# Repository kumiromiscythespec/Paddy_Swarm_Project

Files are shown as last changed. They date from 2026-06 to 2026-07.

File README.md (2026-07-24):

# Paddy Swarm Project Grade 0

田んぼロボットを、まずは無料公開の設計図と試験ログから始めるための公開リポジトリです。

Paddy Swarm Project / 田んぼロボット群プロジェクトは、小規模・家族経営の稲作現場で、人間の負担が大きい作業を小型ロボット群で少しずつ減らすことを目指す試作プロジェクトです。

現段階の目的は、完成品ロボットの販売ではありません。  
まずは **Grade 0** として、3Dプリント用データ、組み立て説明、試験手順、安全ガイド、失敗ログを公開し、興味を持った人が小さく安全に試せる状態を作ります。

---

## 重要：まだ実用機ではありません

このリポジトリのデータは、実験・研究・教育・試作用です。

- 実田んぼで安全に動く保証はありません
- 防水性能は未検証です
- 3Dプリント部品を完全防水容器として信用しないでください
- モーター、バッテリー、制御基板を水に入れる試験は危険です
- 実田んぼは収入源であり、失敗してよい実験場ではありません
- 稲を傷つける可能性のある試験は、必ず小区画・非本番環境から始めてください

推奨する試験順序：

```text
机上
↓
乾いた地面
↓
水槽
↓
柔らかい土
↓
浅泥
↓
水あり模擬環境
↓
小区画・非本番環境
↓
実田んぼ端部
```

---

## Grade 0で公開するもの

- 3Dプリント用STLデータ
- CADデータ置き場
- 組み立て説明書
- 部品番号表
- 推奨フィラメント
- 既製品部品リスト
- 接続テストピース
- サイドフロート試験片
- 浮力試験手順
- 重し配置手順
- 防水BOX配置案
- ギアボックス説明用モデル
- 試験チェックリスト
- 失敗ログ
- 改良履歴

---

## 最初の試験対象

### 1. 接続テストピース

ネジをなるべく使わず、プラモデルのように組み立てるための接続方式を試します。

- スナップフィット
- スライドレール
- 蟻継ぎ
- 印刷ピン
- くさびロック

### 2. サイドフロート断面

水田ローバーが泥や浅水で沈まないための、フロート構造を検討します。

- 密閉空気室
- 発泡材挿入部
- 区画構造
- シャーシ接続レール
- 充電窓逃がし形状

### 3. ギアボックス内部再現モデル

プレゼンや説明に使えるように、左右2モーター、減速ギア、PTO切替、車輪出力、作業ヘッド出力を見える化します。

### 4. 浮力・重心試験用ダミー

電装なしの模型に重しを載せ、水槽で浮力・傾斜・浸水を確認します。

---

## 想定する最小導入：1田スターター

将来的には複数ローバー、充電ステーション、水管理ゲート、直播アーム、除草アーム、高刈り収穫アームへ拡張します。

ただし、最初の導入は **1田スターター** とします。

- ローバー1台
- 基本サイドフロート
- Scout / Field Check Kit
- 交換バッテリー
- 簡易充電・統制ステーション
- スマホ用ローカルWeb UI
- 手動水管理
- 人間回収前提

水管理ゲート、自動ドッキング充電、複数台群制御、ソーラー、直播アーム、高刈り収穫アームは、最初は高級・季節オプションとして扱います。

---

## 将来の拡張構想

### Direct Seeding Arm

育苗工程を減らすための直播アームです。

想定構成：

- 種子ホッパー
- 定量繰り出しローラー
- 浅溝オープナー
- 泥寄せブレード
- 軽鎮圧ローラー

### Weeding Arm

条間中央の初期雑草を処理する除草補助アームです。稲株に近い危険区域は Human Weed Zone として記録し、人間作業に残します。

### High-Cut Harvest Arm

50cm程度の高刈りを標準とする収穫補助アームです。1期目の穂を確保しつつ、茎・葉・節を残し、暖かい年のひこばえ・二番穂を観察します。

### Water Gate

水管理ゲートは高級オプションとして扱います。Grade 0および1田スターターでは、水管理は人間が行います。

---

## リポジトリ構成

```text
.
├── README.md
├── CONTRIBUTING.md
├── .gitignore
├── docs/
│   ├── safety.md
│   ├── test_checklist.md
│   ├── repo_setup_windows.md
│   ├── license_policy.md
│   ├── part_numbering.md
│   └── print_notes/
├── stl/
├── cad/
├── bom/
├── experiments/
├── software/
├── images/
├── tools/
├── print_manifest.csv
└── kit_index.csv
```

---

## 初回印刷の推奨順

1. 接続テストピース
2. サイドフロート断面
3. ギアボックス片側カットモデル
4. 中央シャーシ短縮版
5. 防水BOXダミー
6. Side Charge Zone模型
7. 腹下モジュール交換部
8. ローバー半身モデル
9. 1/2プレゼン模型
10. 実寸フロート試験部品

---

## 協力してほしいこと

- STLを印刷してみる
- PLAとPETGで公差を比較する
- スナップ爪の折れやすさを確認する
- スライドレールのきつさを確認する
- フロート断面の印刷しやすさを確認する
- 水槽で浮力を見る
- 重しを載せて傾き方を見る
- 防水BOX位置の問題を見つける
- ギアボックス模型の説明しやすさを評価する
- 組み立て説明書の分かりにくい点を指摘する
- 失敗ログを共有する

失敗ログは非常に重要です。

---

## 免責

本リポジトリのデータは、実験・研究・教育・試作用です。利用者は自己責任で使用してください。

本プロジェクトは、実田んぼでの動作、防水性能、作物への無害性、収量維持、電気安全、機械安全、法令・農薬ラベル適合性、家畜飼料としての安全性、商用利用時の責任を保証しません。

不明点がある場合は、地域の指導機関、JA、普及指導員、メーカー、専門家に確認してください。

## Common Rover design authority

Current authority: **v2.29.3.9.1**. Start at `CURRENT_COMMON_ROVER_AUTHORITY.md`.

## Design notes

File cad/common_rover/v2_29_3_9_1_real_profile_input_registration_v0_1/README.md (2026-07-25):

# Common Rover v2.29.3.9.1 real profile input registration v0.1

This source-only lane registers two user-confirmed MISUMI purchase records:

- `PROFILE-01`: `NFS5-2020-400`, nominal 20 × 20 mm, 400 mm, quantity 4.
- `PROFILE-02`: `NFSB5-2040-400`, nominal 20 × 40 mm, 400 mm, quantity 4,
  listing colour/finish text `ブラック`.

The order history and supplied Amazon listing references are purchase evidence,
not production cross-section geometry authority. No web lookup is performed.
No customer name, personal order number, shipping address, or payment
information is stored.

Arrival is `PENDING`; measurements, official supplier drawings/tolerances,
accessory compatibility, role assignment, orientation, fit validation, and
structural approval remain `INCOMPLETE` or `HOLD`. Generic MISUMI 5-series
values must not fill missing geometry.

At least two members of each ordered model are assigned separate sample IDs.
The incoming-inspection template records directly accessible external
dimensions at END_A, CENTER, and END_B. Internal cavities and complex slot
geometry require supplier drawings or a separately authorized section cut.

This lane never generates STL, STEP, STP, SVG, or production geometry. All
generated JSON, CSV, Markdown reports, and test results go outside the
repository.

Run with bytecode disabled:

```text
python -B run_unit_tests.py --json <external>/unit_test_results.json --text <external>/unit_test_results.txt
python -B update_production_input_audit.py --repository-root <worktree> --output-dir <external> --baseline-inventory <prior-canonical-artifact>/baseline_tracked_cad_inventory.json
python -B validate_profile_registration.py --repository-root <worktree> --baseline-inventory <prior-canonical-artifact>/baseline_tracked_cad_inventory.json --artifact-dir <external>
```

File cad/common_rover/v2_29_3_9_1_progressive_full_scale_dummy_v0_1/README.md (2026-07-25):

# Progressive Full-Scale Assembly Dummy v0.1

This source-only lane turns the preserved Common Rover v2.29.3.9.1
authority and Assembly Interface v0.1 concepts into a staged, full-scale
placement and fit dummy kit.

The generated parts are not a rover, not load-rated, not waterproof, and not
approved for electrical or field use.  Successful first-side prints remain
usable in the final visual assembly dummy; the workflow does not require a
standalone coupon campaign.

## Authority reuse

`authority_adapter.py` imports the existing corrected Assembly Interface v0.1
authority adapter and reads all controlled dimensions from it.  This lane does
not restate controlled dimensions as independent constants.

The selected architecture is:

- PROFILE-3: printed 20 x 20 envelope-only dummy rails because no supplier
  profile section, T-nut, tolerance, or slot geometry is selected.
- Independent FRONT and REAR BBOX support representations, both marked
  `DUMMY ONLY`, `NO LOAD`, and `NOT STRUCTURAL`.
- Legacy Grade 0 float compatible interface kit with FLOAT-2 visual overlap.
  The audited nominal width is below the registered target, but the
  tolerance/inclination case exceeds it, so operational float-width validation
  remains HOLD.
- Integral positive stops, asymmetric keys, seated indicators, pin windows,
  and a secondary-only retainer cover.

## Physical-connectivity correction

`generate_connectivity_correction.py` preserves the original 19 STL files
byte-for-byte and adds 14 removable, support-free, dummy-only connection
parts.  The resulting 33-part kit has an explicit physical connection graph,
a corrected acyclic print dependency graph, and no loose positioning part.

The correction does not infer PROFILE-3 slots, add direct rail holes, approve
T-nuts, or generate an unknown float body.  Central and float-interface dry
dummy completeness are PASS; float-body and float-equipped completeness
remain HOLD.  AI-10 is reservation-only and remains
`NOT_YET_AUDITED`.

## Printed numbers

The repository precedent `PS-<machine>-<stage>-<category>-<serial>-R00` is
used with machine `PR`, stage `A1`, existing category codes, and a lane-local
300-series allocation.  Since the repository has no global serial allocator,
`GLOBAL_PART_NUMBER_RATIFICATION = HOLD`.

Every exported part is physically engraved with its complete part number and
required orientation/interface/classification markings on a non-functional
identification panel.  Filename-only or metadata-only identification is
rejected.

## Generation

Use the CadQuery environment:

```powershell
C:\Users\yu_ki\Miniforge\envs\paddy-cad\python.exe `
  cad/common_rover/v2_29_3_9_1_progressive_full_scale_dummy_v0_1/generate_dummy_kit.py `
  --output-dir <external-directory>
```

Validation and tests:

```powershell
C:\Users\yu_ki\Miniforge\envs\paddy-cad\python.exe `
  cad/common_rover/v2_29_3_9_1_progressive_full_scale_dummy_v0_1/run_unit_tests.py

C:\Users\yu_ki\Miniforge\envs\paddy-cad\python.exe `
  cad/common_rover/v2_29_3_9_1_progressive_full_scale_dummy_v0_1/validate_dummy_kit.py `
  --artifact-dir <external-directory> --output <external-validation.json>
```

Generated STL, SVG, CSV, JSON, manuals, reports, and caches must stay outside
the repository.

To build and validate the connectivity-corrected artifact:

```powershell
C:\Users\yu_ki\Miniforge\envs\paddy-cad\python.exe `
  cad/common_rover/v2_29_3_9_1_progressive_full_scale_dummy_v0_1/generate_connectivity_correction.py `
  --output-dir <new-external-directory> `
  --baseline-artifact-dir <existing-v0.1-artifact-directory>

C:\Users\yu_ki\Miniforge\envs\paddy-cad\python.exe `
  cad/common_rover/v2_29_3_9_1_progressive_full_scale_dummy_v0_1/validate_connectivity_correction.py `
  --artifact-dir <new-external-directory> `
  --output <new-external-directory>/connectivity_validation.json
```

## Final-gate fixture separation

The base tests accept only manifest schema
`PS_PROGRESSIVE_FULL_SCALE_DUMMY_KIT_V0_1` generated by
`generate_dummy_kit.generate`.  Connectivity tests use the separate
`tests/_connectivity_artifact.py` fixture and accept only schema
`PS_PROGRESSIVE_FULL_SCALE_DUMMY_CONNECTIVITY_CORRECTION_V0_1` generated by
`generate_connectivity_correction.generate`.

`BASE_CORE_OUTPUTS` and `CONNECTIVITY_CORE_OUTPUTS` in
`final_gate_contract.py` are the single authoritative deterministic replay
scopes.  Packaging receipts, test results, checksums, patches, snapshots, and
ZIP files are excluded from core replay.

Run every repository Python command with `python -B` or
`PYTHONDONTWRITEBYTECODE=1`, then scan the complete worktree for `*.pyc`,
`*.pyo`, and `__pycache__`.  Final sealing is performed from an external copy
of `final_gate_sealer.py` plus `final_gate_contract.py`; no repository module
is imported after the final cleanliness scan.

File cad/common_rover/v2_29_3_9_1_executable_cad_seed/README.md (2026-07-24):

# Common Rover v2.29.3.9.1 executable CadQuery seed

This lane is a deterministic, verification-only minimum assembly built from the
sealed `rovers/common_rover/v2.29.3.9.1/` authority. It creates exactly six
axis-aligned CadQuery solids:

1. left FPB rail
2. right FPB rail
3. front crossmember
4. CBOX
5. BBOX
6. battery cassette

The rail and crossmember solids are deliberately classified as
`SIMPLIFIED_TSLOT_AUTHORITY_ENVELOPE`. They are 20 × 20 mm rectangular
verification envelopes, not manufacturing profiles, extrusion selections, or
purchase specifications. No registered maximum-interface-width geometry is
synthesized.

## Run

Use the pinned repository environment:

```powershell
conda run -n paddy-cadquery-280-py312 python -B cad/common_rover/v2_29_3_9_1_executable_cad_seed/validate_seed.py
conda run -n paddy-cadquery-280-py312 python -B cad/common_rover/v2_29_3_9_1_executable_cad_seed/run_unit_tests.py
```

The validator checks single-solid validity, positive finite volume, exact
authority bounding boxes, the two intended rail/crossmember face contacts, zero
unintended volumetric intersections, rail mirror symmetry, the CBOX/BBOX
longitudinal relation, and the three distinct width classes (178 / 286 / 300
mm). Its default STEP roundtrip uses only an operating-system temporary
directory and deletes the file immediately; it never retains a repository STEP
artifact. Pass `--no-step-roundtrip` when only the in-memory gates are needed.

Two dimensionally distinct absolute tolerances are used:

- `linear_tolerance_mm = 1.0e-6` for declared coordinates and bounding boxes.
- `intersection_volume_tolerance_mm3 = 1.0e-9` for Boolean intersection noise
  and verification-only STEP volume replay.

These are exact configuration-contract values. The validator rejects any other
float, including 1.9× or 2× values, NaN, Infinity, zero, and negative values.
The contract values are not compared using themselves as tolerances.

The volume threshold is deliberately much smaller than any modeled feature but
remains a value expressed in mm³; the linear mm tolerance is never reused as a
volume threshold. An intersection volume exactly at the volume tolerance
passes, while any larger volume fails when no volumetric overlap is expected.

Validation is fail-closed. Boolean exceptions, negative/non-finite Boolean
volumes, missing or non-CadQuery objects, and missing/duplicate required
authority records produce structured blockers and `FAIL`. Exception messages,
temporary paths, and memory addresses are not included in deterministic JSON.
Battery placement is confirmed only after all six required hardware-envelope
records have each been found exactly once.

The build result is also closed over the exact six required component IDs.
Missing or extra keys, `None`, another object type, or a non-null solid count
other than six fails validation.

All 15 possible unordered pairs are listed in the report policy matrix. Four
pairs are Boolean checked (the two rail/crossmember contacts, rail separation,
and CBOX/BBOX contact), Battery/BBOX is envelope-checked as
`INTENDED_CONTAINMENT`, and the remaining ten pairs are explicitly
`NOT_AUTHORIZED_FOR_RELATION_ASSERTION`. The reported unintended-intersection
count applies only to the four Boolean-checked pairs; it is not a claim about
unauthorized pairs, and the intentional Battery/BBOX containment overlap is not
counted as unintended.

The successful state is `PASS_WITH_HOLD`. Manufacturing, purchase, field
deployment, waterproofing, structural-strength, executable-CAD release, and
manufacturing-release statuses remain held or unapproved. This seed does not
resolve those authority holds.

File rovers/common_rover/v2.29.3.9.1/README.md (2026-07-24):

# Common Rover v2.29.3.9.1 correction lane

Correction-only authority lane. It unifies lower adapters on rail bottom slots,
upper torque on the front-crossmember top slot, validates all 60 body T-slot
anchors across registries, and resolves the candidate manifest relative to the
version lane. Body geometry, axes, envelopes, width, and release holds remain
identical to v2.29.3.9.

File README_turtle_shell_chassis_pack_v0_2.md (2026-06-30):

# Paddy Swarm Turtle Shell Chassis CAD Pack v0.2

This pack updates the Paddy Swarm amphibious rover test body with a **standard turtle shell cover** and a revised center chassis interface.

## Concept

The turtle shell is now treated as a standard first-defense layer:

- rain guard
- mud splash guard
- shallow waterline / tilt guard
- rollover scuff guard
- future solar/perovskite mounting surface
- mascot/trademark shape

It is **not** treated as the only waterproof enclosure in v0.2. The correct early structure is:

```text
outer standard turtle shell
↓
inner dry cassette / battery cassette
↓
low center battery tray and chassis
```

## Important safety rule

Do not remove the inner waterproof/dry cassette yet. FDM printed shells can leak through layer lines, seams, cracks, screw holes, and cable openings. Use this CAD pack for fit, float, tilt, splash, and handling tests before adding electronics.

## Main files

- `stl/hull_v0_2/PSR-HU-020-R00_center_chassis_segment_v0_2.stl`
- `stl/hull_v0_2/PSR-SHL-001F-R00_standard_turtle_shell_front.stl`
- `stl/hull_v0_2/PSR-SHL-001R-R00_standard_turtle_shell_rear.stl`
- `stl/hull_v0_2/PSR-PWR-010-R00_inner_dry_cassette_dummy.stl`
- `stl/hull_v0_2/PSR-PWR-011-R00_low_center_battery_tray.stl`
- `stl/hull_v0_2/PSR-SHL-003-R00_charge_scute_window_insert.stl`
- `stl/hull_v0_2/PSR-ASM-001-R00_full_rover_turtle_shell_reference_assembly.stl`

## Print priority

1. `PSR-SHL-000-R00_shell_mount_base_gauge.stl` in PLA
2. `PSR-HU-020-R00_center_chassis_segment_v0_2.stl` in PLA
3. `PSR-PWR-010-R00_inner_dry_cassette_dummy.stl` in PLA
4. `PSR-SHL-001F/R` shell halves in PLA for fit check
5. Repeat shell halves in PETG for water-adjacent tests
6. Print `PSR-SHL-003` Charge Scute insert only after confirming top-charge placement

## Bambu Lab A1 note

The shell is split into front/rear halves so printable parts stay near or below the A1 print area. The full assembly STL is a visual reference and is not meant to be printed as one piece.

## Field-use warning

This is Grade 0 / early Grade 1 CAD. Do not mount a live battery or controller until dry tests, splash tests, tilt tests, and paper-towel leak checks are complete.

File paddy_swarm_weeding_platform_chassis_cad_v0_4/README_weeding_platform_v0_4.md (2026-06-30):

# Paddy Swarm Weeding Platform Chassis CAD v0.4

This pack updates the Paddy Swarm work-platform CAD toward a **base chassis + under-belly weeding machine** configuration.

This version intentionally does **not** include the removable direct-seeding / germinated-seed module or the high-cut harvest module. Front and rear option receiver interfaces remain as blank sockets so future modules can be attached without rebuilding the base chassis.

## Design target

- Four-wheel base chassis
- Under-belly weeding module for weeding season
- Removable left/right side floats for shallow-water and mud tests
- Approximately 15 cm water-condition concept, with soft mud sink-in considered
- Low water-shedding protective cover, not a turtle-shaped decorative body
- Charge Scute / top charge area retained
- Solar / perovskite-ready flat area retained, but no solar panel included
- Inner dry cassette retained as second protection layer

## Important safety note

These STL files are Grade 0 / early mechanical test geometry. They are not waterproof-certified and are not validated for real paddy-field operation. Do not mount electronics or batteries for water tests until dry-cassette and leakage tests are completed.

## Print order

1. `PSR-WP-101-R00_base_chassis_four_wheel_weeding_ready.stl`
2. `PSR-WD-101-R00_belly_weeding_module_carrier.stl`
3. `PSR-WD-102-R00_belly_weeding_stirrer_tine_unit.stl`
4. `PSR-FLT-101-R00_removable_side_float_pair_15cm_water.stl`
5. `PSR-WH-101-R00_tpu_low_damage_lug_wheel_dummy.stl`
6. `PSR-WP-102-R00_low_protective_cover_charge_solar_ready.stl`

`PSR-ASM-103` is a reference assembly and is not intended to be printed as one piece.

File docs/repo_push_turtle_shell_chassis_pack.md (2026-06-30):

# Repo push guide: Turtle Shell Chassis v0.2

From your local repository root:

```powershell
cd C:\Paddy_Swarm_Project
Expand-Archive -Path .\paddy_swarm_turtle_shell_chassis_cad_v0_2.zip -DestinationPath . -Force
git status
git add .
git commit -m "Add standard turtle shell chassis CAD v0.2"
git push
```

Recommended commit note:

- Adds standard turtle shell cover concept
- Updates chassis with shell mount rails and inner dry cassette bay
- Adds Charge Scute wireless charge window dummy
- Keeps inner dry cassette as second defense layer

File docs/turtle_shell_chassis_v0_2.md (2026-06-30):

# Paddy Swarm Standard Turtle Shell + Chassis v0.2

## Purpose

This revision changes the turtle shell from a future solar luxury part into a standard protective body cover.

The shell is intended to protect expensive electronics and motors from direct rain, mud splash, shallow waterline contact during tilt, and light rollover scuffing.

## Design decision

The shell is a first defense layer, not the final waterproof container.

```text
Standard Turtle Shell = first defense
Inner Dry Cassette = second defense
Battery Cassette = protected power module
Chassis = low-center structure and float/motor interface
```

## Why the chassis needed an update

A standard shell requires new hardpoints:

- shell mount rails
- orientation key so the shell cannot be installed backwards
- inner dry cassette bay
- low-center battery tray interface
- charge module / charge scute reserved area
- future solar-ready surface planning

## Charge Scute

The Charge Scute is a non-metallic window zone for future top wireless charging.

Rules:

- do not put metal screws near the coil window
- do not charge directly into a lithium battery
- use a receiver module, voltage regulation, CC/CV charger, BMS, fuse, and temperature monitoring
- keep cassette charging and wired charging compatible through the common Power Bay concept

## Solar-ready shell

The v0.2 shell does not include solar panels. It only reserves upper surface area for:

- future removable solar panel mount
- perovskite coating experiments
- adhesive panel tests

The rover must remain fully useful without solar.

## Tilt and waterline test

Recommended first tests:

1. Mount shell to chassis with no electronics.
2. Put paper towels inside the dry cassette dummy.
3. Add ballast equivalent to expected electronics/battery weight.
4. Float in water tray/tank.
5. Tilt to 5°, 10°, and 15°.
6. Confirm water runs off the shell and does not pool.
7. Confirm no water drips into the dry cassette zone.
8. Log whether shell lips touch water and whether the rover self-righting tendency worsens.

## Remaining risks

- Shell raises center of gravity if printed too thick.
- Shell can catch wind.
- Shell can hold heat if ventilation is poor.
- Shell can trap condensation if sealed incorrectly.
- FDM print layer lines are not waterproof by default.
- Motor shaft exits still need separate mud and water guards.

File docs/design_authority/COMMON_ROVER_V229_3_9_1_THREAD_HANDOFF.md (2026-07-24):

# Common Rover v2.29.3.9.1 cross-thread handoff

Correction-only authority. CBOX/BBOX/cassette, rails, crossmember, axes,
envelopes, 286 mm operational width, output Y=-222…-212, and release holds are
unchanged from v2.29.3.9. Lower adapters are BOTTOM_SLOT on RAIL-L/R-BOTTOM.
Upper torque is XMEMBER-TOP / TOP_SLOT_OF_FRONT_CROSSMEMBER. Cross-registry
validation is explicit and complete for 60/60 anchors.

Copyable: `Authority=v2.29.3.9.1; correction-only; lower=BOTTOM_SLOT; upper-torque=XMEMBER-TOP; cross-registry=60/60; width=286; CAD/manufacturing=HOLD.`

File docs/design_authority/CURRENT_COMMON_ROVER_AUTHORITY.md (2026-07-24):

# Design authority pointer

Current Common Rover authority: **v2.29.3.9.1**.

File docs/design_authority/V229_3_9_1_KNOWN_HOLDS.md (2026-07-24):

# Known holds

CadQuery/actual solids/STEP/STL are not run. Exact T-slot/T-nut product,
strength, waterproofing, electrical safety, thermal behavior, manufacturing,
purchase, and field deployment remain unapproved or unvalidated.

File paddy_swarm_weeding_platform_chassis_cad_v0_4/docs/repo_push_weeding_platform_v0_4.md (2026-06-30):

# Push Paddy Swarm Weeding Platform v0.4 to GitHub

```powershell
cd C:\Paddy_Swarm_Project
Expand-Archive -Path .\paddy_swarm_weeding_platform_chassis_cad_v0_4.zip -DestinationPath . -Force
git status
git add .
git commit -m "Add weeding platform base chassis CAD v0.4"
git push
```

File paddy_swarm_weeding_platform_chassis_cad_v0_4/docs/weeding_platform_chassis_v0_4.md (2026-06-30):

# Paddy Swarm Weeding Platform Chassis v0.4

## What changed from v0.3

v0.3 tried to represent a generic work platform with direct seeding, belly weeding, and high-cut harvesting examples. In this v0.4 CAD pack, the design is narrowed to the **weeding-season complete configuration**:

- Base chassis
- Four wheels
- Removable side floats
- Low protective cover
- Inner dry cassette
- Under-belly weeding module

The following are **not included as physical modules** in this pack:

- Germinated-seed direct-seeding module
- High-cut harvest arm

Only the blank front/rear receiver sockets remain.

## Field assumptions

- Water depth target for concept review: around 15 cm
- Soft mud sink-in is expected
- Wheels may partly sink; side floats help maintain buoyancy and side protection
- Under-belly weeding module should disturb weeds and surface mud, but not dig aggressively
- 180-degree rotation in crop lanes remains discouraged; Reverse-First Navigation is still assumed

## Mechanical philosophy

The rover is a paddy-field work platform, not a turtle-shaped vehicle. The cover is low and functional. The shell-like cover is used for water-shedding and protection only.

The side floats are removable because they may not be needed for every test, and the user should be able to compare:

- base chassis without floats
- base chassis with floats
- float size variations
- float position variations

## Weeding module concept

The under-belly weeding module is represented by:

- slide-in carrier frame
- height-adjustment posts
- mud float skids
- stirrer axle
- flexible tine array
- guard bars

The module is intended for print-fit and clearance testing first. Rotation, PTO, motor coupling, sealing, and weed effectiveness require separate experiments.

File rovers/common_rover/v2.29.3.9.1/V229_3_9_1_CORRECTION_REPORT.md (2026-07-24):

# v2.29.3.9.1 correction report

- Lower adapter: `BOTTOM_SLOT`, host slots `RAIL-L-BOTTOM` / `RAIL-R-BOTTOM`.
- Upper torque: `XMEMBER-TOP`, normalized `TOP_SLOT`, semantic role
  `TOP_SLOT_OF_FRONT_CROSSMEMBER`.
- Join: explicit `slot_zone_id`; no fallback or component-name inference.
- Validation: source-relative and independent of current working directory.

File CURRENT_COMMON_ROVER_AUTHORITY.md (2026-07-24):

# Current Paddy Swarm Common Rover Authority

Current authority: **v2.29.3.9.1**

Precedence: v2.29.3.9.1 > v2.29.3.9 > v2.29.3.8 > v2.29.3.7 > v2.29.3.6 > v2.29.3.5 > v2.28.2

This is a correction-only revision of the v2.29.3.9 FPB 20×20 T-slot frame.
Lower adapters use BOTTOM_SLOT; upper torque uses XMEMBER-TOP; all 60/60 body
T-slot anchors pass explicit cross-registry validation.

Body dimensions and the 138×20×20 mm front crossmember are unchanged. Registered
maximum-interface width is 286 mm. Actual solid is not run.

GITHUB_EXECUTABLE_CAD_RELEASE = HOLD
GITHUB_MANUFACTURING_RELEASE = HOLD
PURCHASE_STATUS = NOT_APPROVED
FIELD_DEPLOYMENT_STATUS = NOT_APPROVED

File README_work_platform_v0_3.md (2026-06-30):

# Paddy Swarm Work Platform Chassis CAD Pack v0.3

田植え直撒き・腹下除草・高刈りアームに対応するため、亀の体に似せることよりも、作業モジュールを載せるための四輪作業プラットフォームとして再設計したCAD/STLパックです。

## 設計目的

- 中央 Safety Path 運用を前提にした四輪低重心ローバー
- 前方に除草・直播・田植え系アタッチメントを接続
- 腹下に除草撹拌ユニットを搭載
- 後方に高刈り・収穫補助アームを接続
- 上面は亀型マスコット優先ではなく、低い防水・防泥カバーとして整理
- Charge Scute / ソーラー対応面は残すが、作業機能を優先

## 注意

このパックは Grade 0 / R00 の概念・寸法確認用です。実田んぼ投入、電装搭載、水没試験には使わないでください。FDM印刷品は完全防水ではありません。

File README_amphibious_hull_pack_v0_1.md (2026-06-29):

# Paddy Swarm Amphibious Hull CAD Pack v0.1 / 水陸両用型ローバー船体CADパック

This pack adds the first printable CAD/STL set for the Paddy Swarm Amphibious Hull concept.

このパックは、Paddy Swarm Project の「水陸両用型ローバー船体 v0.1」をGrade 0試験用に3Dプリントできる形へ落としたものです。

## Important / 重要

These parts are **experimental Grade 0 parts**. They are not waterproof, not field-proven, and not a finished rover.

- Do not put electronics or batteries in water.
- Do not use these parts in a real paddy field first.
- Start with PLA fit checks, then PETG water-tank tests.
- Use foam inside float trays during water tests.
- Seal seams only for controlled tests using tape/silicone.
- If a paper towel placed in the waterproof-box position gets wet, the design fails the water-ingress test.

## Contents

- `stl/hull_v0_1/` — printable STL files
- `cad/hull_v0_1/generate_amphibious_hull_v0_1.py` — source generator used to create the STL files
- `docs/amphibious_hull_v0_1.md` — design notes and assembly concept
- `docs/print_notes/PSR-HU-R00.md` — print notes
- `print_manifest.csv` — part sizes and print notes
- `kit_index.csv` — repo index entries

## First print recommendation

Print in this order:

1. `PSR-HU-001-R00_central_hull_short_frame.stl` in PLA
2. `PSR-HU-013-R00_ballast_test_tray.stl` in PLA
3. One float tray, e.g. `PSR-HU-003-R00_left_float_mid_tray.stl`, in PLA
4. Same float tray in PETG
5. Float lid and seam joiner clips
6. Water-tank test with no electronics

## Repository merge

From the repo root:

```powershell
Expand-Archive -Path .\paddy_swarm_amphibious_hull_cad_v0_1.zip -DestinationPath . -Force
git add .
git commit -m "Add amphibious hull Grade 0 CAD pack v0.1"
git push
```

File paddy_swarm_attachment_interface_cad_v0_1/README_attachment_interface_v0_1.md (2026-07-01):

# Paddy Swarm Attachment Interface CAD v0.1

This package introduces the **Paddy Swarm Attachment Interface Standard v0.1**.

Purpose:
- Keep the rover body upgradable while keeping attachment locations fixed.
- Move direct seeding / planting-style modules to the **rear** so the rover wheels do not run over freshly placed germinated seed.
- Reserve the **front** attachment ports for high-cut harvest, camera-linked work, and operations that need visual confirmation.
- Keep belly weeding as a central underbody module.

Important: this is a **Grade 0 / mock-up CAD pack**. Shafts, pins, bushings and springs are included as 3D-printable dummy parts so a physical model can be assembled cheaply. Field-use versions may need metal shafts, bearings, bushings, springs, seals, and stronger hardware.

## Fixed interface concept

Coordinate convention:
- X: left/right
- Y: front/rear
- Z: up/down
- Body center is the origin.

Nominal fixed positions:
- Front-left port: X=-70 mm, Y=+230 mm
- Front-right port: X=+70 mm, Y=+230 mm
- Rear-left port: X=-70 mm, Y=-230 mm
- Rear-right port: X=+70 mm, Y=-230 mm
- Nominal port height: Z=65 mm

These values are the v0.1 interface reference. Future rover chassis updates should preserve these port positions or provide adapter plates.

## Attachment allocation rule

- Front two ports: high-cut harvest, camera-linked tools, inspection tools.
- Rear two ports: direct seeding, planting, replanting modules.
- Belly rail: underbody weeding modules.
- Side mounts: floats, guards, recovery aids.

## Included update

- Base chassis v0.5 with four fixed ports.
- Rear-mounted 3-unit direct seeding mock-up using the rear-left and rear-right ports.
- Front high-cut interface bridge gauge, not an actual cutter.
- 3D-printed dummy shafts, pins, springs and fasteners for low-cost model assembly.
- Stackable hopper extension walls with no lid, assuming wet germinated seed and non-rain-avoidance operation.

## Notes

The direct seeding module here is intentionally placed at the rear. It is meant to place germinated seed after the wheels pass, closer to the logic of a transplanter. The module includes a light skid/opener concept for shallow placement and wheel-track correction, but actual seed depth must be validated in tray and mud tests.

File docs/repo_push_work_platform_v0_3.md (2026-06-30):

# GitHub push手順

ローカルの `C:\Paddy_Swarm_Project` にZIPを置いた前提です。

```powershell
cd C:\Paddy_Swarm_Project
Expand-Archive -Path .\paddy_swarm_work_platform_chassis_cad_v0_3.zip -DestinationPath . -Force
git status
git add .
git commit -m "Add four-wheel work platform chassis CAD v0.3"
git push
```

## 推奨コミット内容

- `stl/work_platform_v0_3/`
- `cad/work_platform_v0_3/generate_work_platform_v0_3.py`
- `docs/work_platform_chassis_v0_3.md`
- `docs/print_notes/PSR-WP-R00.md`
- `print_manifest_work_platform_v0_3.csv`
- `kit_index_work_platform_v0_3.csv`

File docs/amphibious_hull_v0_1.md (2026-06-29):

# docs/amphibious_hull_v0_1.md

# Paddy Swarm Amphibious Hull v0.1

## Purpose

This is the first Grade 0 CAD pack for the Paddy Swarm amphibious hull concept.

Design principle:

```text
Instead of attaching floats to a vehicle,
design a floating small hull and attach drive/working modules to it.
```

日本語で言えば、これは「車体にフロートを足す」のではなく、**浮く船体に足回りと作業アームを付ける**設計です。

## Target

- 30cm rice-row spacing awareness
- Narrow hull, around 220–240mm max concept width
- Left/right side floats as primary buoyancy
- Low center of gravity
- Open-top float trays for foam insertion and inspection
- No electronics during Grade 0 water tests

## Parts

| Part No. | Name |
|---|---|
| PSR-HU-001-R00 | Central hull short frame |
| PSR-HU-002-R00 | Left float front tray |
| PSR-HU-003-R00 | Left float mid tray |
| PSR-HU-004-R00 | Left float rear tray |
| PSR-HU-005-R00 | Right float front tray |
| PSR-HU-006-R00 | Right float mid tray |
| PSR-HU-007-R00 | Right float rear tray |
| PSR-HU-008-R00 | Bow mud deflector concept |
| PSR-HU-010-R00 | Waterproof box dummy |
| PSR-HU-012-R00 | Belly module rail sample |
| PSR-HU-013-R00 | Ballast test tray |
| PSR-HU-015-R00 | Generic float segment lid |
| PSR-HU-016-R00 | Float seam joiner clip |

## Float structure

Each float segment is an open tray with:

- bottom plate
- side walls
- internal baffles
- foam insertion space
- waterline raised bands
- lid part
- seam clips for multi-segment tests

This is not a sealed boat hull. It is a Grade 0 test structure.

## Buoyancy test concept

Use no electronics. Put foam inside trays, mount lids, temporarily seal seams with tape or silicone, then test in a water tank.

Minimum checks:

```text
normal posture
front-up 10 degrees
front-down 10 degrees
left tilt 10 degrees
right tilt 10 degrees
light rocking
paper towel at waterproof-box position
```

Pass condition:

```text
paper towel stays dry
waterline stays below danger area
no sudden sinking if one segment leaks
```

## Print notes

- PLA: fit test and visual test
- PETG: water-tank test parts
- TPU: not used in this pack
- Use brim for tall float trays
- Print float trays upright/open-side up
- Do not assume FDM parts are watertight

## Next iteration ideas

- Add readable embossed labels
- Improve seam connector geometry
- Add true dovetail keys
- Create scaled full assembly jig
- Add optional wide-test float
- Add side-charge cutout version
- Add watertight lid gasket channel

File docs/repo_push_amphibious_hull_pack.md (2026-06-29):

# docs/repo_push_amphibious_hull_pack.md

# How to add this CAD pack to the public repo

Put `paddy_swarm_amphibious_hull_cad_v0_1.zip` in your repo root, for example:

```text
C:\Paddy_Swarm_Project
```

Then run PowerShell:

```powershell
cd C:\Paddy_Swarm_Project
Expand-Archive -Path .\paddy_swarm_amphibious_hull_cad_v0_1.zip -DestinationPath . -Force
git status
git add .
git commit -m "Add amphibious hull Grade 0 CAD pack v0.1"
git push
```

If the ZIP file itself appears in `git status`, do not commit the ZIP. Commit the extracted files only.

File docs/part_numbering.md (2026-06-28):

# Part Numbering

## Machine codes

- PR = Paddy Rover
- PP = Paddy Planter
- HU = Harvest Unit
- WU = Weeding Unit
- ST = Station
- PB = Power Box
- SC = Solar Carapace

## Stage codes

- A0 = Alpha-0
- A1 = Alpha-1
- R0 = Row-0
- P0 = Planter-0
- H0 = Harvest bench test
- W0 = Weeding bench test
- S0 = Station prototype

## Category codes

- BDY = Body / exterior
- FRM = Frame
- MNT = Mount
- CBL = Cable guide
- FND = Fender
- FLT = Float
- SKD = Skid
- WHL = Wheel
- PAD = Foot pad
- ARM = Arm
- GDE = Guide
- CVR = Cover
- BOX = Box holder
- TRAY = Tray
- DOCK = Dock part
- SEN = Sensor mount
- CAM = Camera mount
- BAT = Battery tray
- SBC = Single board computer mount
- CHU = Chute
- DEPTH = Depth gauge

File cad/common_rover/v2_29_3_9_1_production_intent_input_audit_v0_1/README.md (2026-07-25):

# Common Rover v2.29.3.9.1 production-intent input audit v0.1

This source-only lane audits whether real manufacturing inputs exist before any
production-intent geometry is generated. It does not create STL, STEP, STP, or
SVG files. All generated reports must be written outside the repository.

The existing 33 progressive full-scale dummy STL files remain `DUMMY ONLY / NO
LOAD / NOT STRUCTURAL / PROFILE-3 ONLY`. They are not manufacturing parts,
real-rover parts, structural parts, or evidence of compatibility with an
actual aluminum extrusion. Their geometry and part numbers are not
automatically reusable, and removing the dummy marking does not promote them
to production.

The corrected repository-output contract permits the 181 tracked STL and 109
tracked STEP/STP files sealed at base
`242737507c1f94811ff309b36905525057761c45`, provided every baseline file is
unchanged. Added, modified, deleted, or untracked CAD output fails the audit.
The filesystem scan is independent of `.gitignore`.

The canonical inventory algorithm is
`SHA256_OF_UTF8_BYTEWISE_SORTED_POSIX_PATH_RECORDS_V1`:

1. convert backslashes to `/`, reject leading `./`, absolute paths,
   noncanonical segments, control characters, and duplicate canonical paths;
2. validate every file SHA-256 and lowercase it;
3. sort records by `record["path"].encode("utf-8")`;
4. encode each record as
   `<lowercase_sha256><two ASCII spaces><canonical_posix_path><LF>`;
5. concatenate the UTF-8 bytes and SHA-256 the complete payload.

The JSON record array and CSV rows must be identical and in that canonical
order. The receipt, recorded JSON hash, calculated hash, and independent
reversed/shuffled replays must all match.

Run with bytecode disabled:

```text
python -B build_canonical_baseline_inventory.py --repository-root <worktree> --output-dir <external>
python -B replay_canonical_inventory.py --artifact-dir <external>
python -B run_unit_tests.py --json <external>/unit_test_results.json --text <external>/unit_test_results.txt
python -B generate_production_input_audit.py --repository-root <worktree> --output-dir <external> --baseline-inventory <external>/baseline_tracked_cad_inventory.json
python -B validate_production_input_audit.py --repository-root <worktree> --artifact-dir <external>
```

Expected outcome is `PASS_WITH_HOLD`: the audit is valid, but production STL
generation, manufacturing, purchase, and field deployment remain unapproved
until all actual inputs are closed.

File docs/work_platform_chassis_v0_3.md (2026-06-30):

# Paddy Swarm Work Platform Chassis v0.3

## 変更理由

前回の標準亀甲羅ローバー案は、ブランド性・水切り・防泥ガードとして有効でした。  
しかし、実際の目的は「亀に似た車体」を作ることではなく、以下の作業に対応できる低コストな水田作業プラットフォームを作ることです。

- 田植え・直播
- 腹下除草
- 高刈り収穫補助
- 前進作業、後退帰還
- Safety Path から左右作業レーンへ入る運用

そのため v0.3 では、外観よりもアタッチメント接続・腹下空間・低重心・四輪レイアウトを優先しました。

## 基本構成

| 部品 | 目的 |
|---|---|
| PSR-WP-001 | 四輪作業シャーシ本体。腹下モジュールレール、前後マウント、低重心トレーを含む |
| PSR-WP-002 | 前方クイックアタッチメントマウント。除草・直播・田植え系を想定 |
| PSR-WP-003 | 後方マウント。高刈り・収穫補助・後部処理系を想定 |
| PSR-WP-004 | 腹下除草モジュールのダミー。撹拌軸・タインのクリアランス確認用 |
| PSR-WP-005 | 直播・田植えモジュールダミー。ホッパー・繰り出し・浅溝オープナーを想定 |
| PSR-WP-006 | 高刈り収穫アームダミー。刈刃・穂ガイド・受けトレーを想定 |
| PSR-WP-007 | 低い機能優先カバー。水切り、Charge Scute、ソーラー対応面を含む |
| PSR-WP-008 | 側面フロートペア。Safety Path幅での安定化想定 |
| PSR-WH-010 | TPUラグタイヤのダミー |
| PSR-ASM-002 | 全体参照アセンブリ。印刷用ではなく全体把握用 |

## 重要な設計方針

### 四輪化

1輪を各コーナーに配置します。  
差動制御・左右駆動・将来の四輪独立制御を検討できますが、R00ではまず見た目と配置の確認用です。

### 前方マウント

前方には以下の作業を想定したクイックマウントを置きます。

- 除草用前方ガイド
- 直播ユニット
- 小苗田植え/補植ユニット
- 浅溝オープナー
- 種子ホッパー

### 腹下除草

腹下には除草撹拌ユニットを通せる中央クリアランスを残します。  
R00では撹拌軸ダミーとタインダミーを入れ、地面・泥面との干渉確認を目的にします。

### 後方高刈りアーム

後方には高刈り・収穫補助のためのヒンジ耳とマウントを置きます。  
初期は穂先を切る・受ける・後方処理系に渡すための空間検討用です。

### 低い保護カバー

亀の体に似せるのではなく、低い水切りカバーとして再定義しています。  
上面には以下を残します。

- Charge Scute 予定地
- ソーラー後付け/ペロブスカイト塗布予定面
- 左右水切りリップ

ただし、カバーは第一防衛層です。内部防水カセットはまだ必要です。

## 試験順序

1. PSR-WP-001 をPLAで印刷し、反り・サイズ感・腹下クリアランスを確認
2. PSR-WP-002 / 003 を印刷し、前後マウントの位置を見る
3. PSR-WP-004 を腹下へ仮置きし、除草タインの地面干渉を見る
4. PSR-WP-005 を前方へ仮置きし、重心変化を見る
5. PSR-WP-006 を後方へ仮置きし、後方アームで転倒しないか確認
6. PSR-WP-007 を載せ、水切り・アクセス性・充電窓位置を見る
7. PSR-ASM-002 は印刷せず、全体把握・レンダリング用に使う

## 現場上の注意

- この形はSafety Path運用を前提にする
- 条間に入って作業し、基本は後退帰還する
- 180度その場旋回は標準禁止
- 腹下除草ユニット使用中の旋回は避ける
- 高刈りアームは重心を後ろに動かすので、必ずダミー荷重で確認する
- 直播ホッパーは種子量により重心が変わる

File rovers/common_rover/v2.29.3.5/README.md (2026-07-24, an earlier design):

> [!WARNING]
> **Status: EXPERIMENTAL_PREFLIGHT_SOURCE**
>
> This revision is a design-authority and pre-CadQuery validation snapshot.
> CadQuery/OCP execution has not yet been performed.
>
> No actual Solid, STEP, STL, rendered PNG, collision result,
> minimum-assembly result, structural-strength result, waterproof result,
> manufacturing release, purchase approval, or field-deployment approval
> is provided by this revision.
# Common Rover v2.29.3.5

Contract:
`PS-COMMON-ROVER-V229_3_5-LOOP001-HOLE-AUTHORITY-FULL-RUNNER-WIRING-CLOSURE-001`

This isolated lane determines rail-hole responsibility from attachment, joint,
load-path, part-role, and measurement authority before any reachability check.
Unreachable instances are never silently converted to stale records and no
coordinate is moved without authority.

The 24 rail-referencing instances account as:

- four required FG-006 rail through holes;
- eight measurement holds in FG-002 and FG-004;
- twelve design contradictions in FG-008, FG-009, and FG-020.

Static full-circle inspection identifies four interior candidates, five
edge-breakout candidates, and fifteen exterior/contradiction candidates. The
five boundary circles are not generated as normal holes or reinterpreted as
slots/notches.

`full_loop_runner.py` is the single 24-stage execution authority. It wires
required-hole generation, STEP reimport, visualization STL validation, actual
Solid rendering, minimum-assembly propagation, receipt consumption, final
gate, package, and final ZIP seal. CadQuery absence exits 20 and never claims
Solid, STEP, STL, PNG, or assembly PASS.

The rail remains `METAL_PART_CAD_VALIDATION`, not a production print target.
The rail/front-crossmember joint remains `UNDEFINED_MEASUREMENT_HOLD`, so
minimum-assembly and LOOP-001 final PASS are blocked.

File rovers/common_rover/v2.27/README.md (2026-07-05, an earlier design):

# Paddy Swarm Common Rover v2.27

## 日本語

### 概要

このフォルダは、Paddy Swarm Project / 田んぼロボット群プロジェクト向けの **Common Rover v2.27** 印刷・組み立て用データです。

v2.27は、実田んぼ投入機ではなく、以下を確認するための **低負荷3Dプリント模型 / 試作検証機** です。

- 足回りの組み立て確認
- ギアボックス内部模型の確認
- TPU一体タイヤの取り付け確認
- BBOX / CBOX の前後配置確認
- PTOと緊急停止ボタンの干渉確認
- フロート装備時の浮力・姿勢確認
- 15cm水深を想定した水槽・たらい試験
- 部品干渉、組み立て順、修正点の発見

このデータは、完成品・実用品・防水保証品ではありません。

---

### 重要な安全注意

このv2.27は、**組み立て確認・浮力確認・干渉確認用の低負荷3Dプリント模型**です。

以下を必ず守ってください。

- 電子部品を搭載した状態で水試験をしないでください。
- 実田んぼに投入しないでください。
- 3Dプリント防水BOXを、そのまま実用防水筐体として扱わないでください。
- 水試験では、バッテリー・基板・モーターを入れず、重りで重量だけを再現してください。
- 15cm水深試験では、フロート装備を必須としてください。
- PTO、モーター駆動、バッテリー、防水、充電系、非常停止系は実地検証済みではありません。
- 緊急停止ボタンは、PTOユニット装着時でも必ず押せる位置にしてください。
- フロートは標準装備として扱いますが、実際に浮くかどうかは水槽試験で確認してください。

---

### v2.27の重要設計方針

#### 1. BBOX / CBOX は前後方向に配置する

BBOX-BDY と CBOX-BDY は、車体の左右方向に並べてはいけません。

正しい配置:

```text
前方 FRONT
  BBOX-BDY  電源 / バッテリー系
  CBOX-BDY  制御 / 通信系
後方 REAR
```

禁止配置:

```text
BBOX-BDY + CBOX-BDY を左右横並び
```

横並びにすると、30cm条間の幅制限を超える可能性が高くなります。

---

#### 2. タイヤは別体ゴムタイヤ前提ではない

v2.27の以下の部品は、TPUで印刷する **一体タイヤ / 接地ホイール模型** です。

```text
PS-RV227-WHL-FL
PS-RV227-WHL-FR
PS-RV227-WHL-RL
PS-RV227-WHL-RR
```

市販ゴムタイヤを別途履かせる設計ではありません。

将来的に市販ゴムタイヤ仕様にする場合は、別バージョンとして、ホイールリム・タイヤ内径・外径・ビード形状を再設計してください。

---

#### 3. フロートは標準装備

15cm水深 + 泥への沈み込みを想定すると、タイヤと防水BOXだけでは水没リスクがあります。

v2.27では、以下のフロート関連部品を標準装備として扱います。

```text
PS-RV227-FLT-L
PS-RV227-FLT-R
PS-RV227-HULL-SKID
PS-RV227-FLT-BRACKET-S
PS-RV227-FLT-RCV-L
PS-RV227-FLT-RCV-R
PS-RV227-FLT-RCV-FR-S
PS-RV227-FLT-STRAP-S
```

ただし、3Dプリント品は積層隙間やピンホールから浸水する可能性があります。

水試験では、必要に応じて以下を併用してください。

- 発泡材
- 密閉PETボトル
- EVA / 発泡ブロック
- 防水塗装
- エポキシ封止
- ウレタンコート
- シリコンシール

---

#### 4. PTOと緊急停止ボタンは分離する

v2.27では、PTO接続部と緊急停止ボタンの干渉を避けるため、以下の方針にしています。

- PTOは前面下側の接続部に配置
- 緊急停止ボタン / 操作パネルは高置き
- `PS-RV227-RCP-BRKT` により、操作パネルをPTOから離す
- PTOユニットを装着した状態でも、緊急停止ボタンを押せることを必須条件とする

---

### 推奨印刷セット

このフォルダには、複数の印刷セットが含まれる場合があります。

低負荷の稼動模型として印刷する場合:

```text
dense_rigid_plus_metal
dense_tpu_only
```

実物の金属軸を用意する場合:

```text
dense_rigid_only
dense_tpu_only
```

注意:

```text
dense_rigid_plus_metal と dense_rigid_only を両方印刷しないでください。
部品が重複します。
```

---

### 材料と印刷量の目安

撮影されたスライサー表示を元にした概算では、v2.27一式は以下の規模です。

```text
PETG/PLA:
  約 84h22m
  約 2781.91g

TPU:
  約 21h05m
  約 302.32g

合計:
  約 105h27m
  約 3084.23g
```

実際の印刷時間と材料量は、プリンター、ノズル径、積層ピッチ、インフィル、サポート設定、フィラメント種類によって変わります。

---

### 組み立て前の確認

印刷前・組み立て前に、必ず以下を確認してください。

```text
1. BBOX/CBOXが前後方向に配置されているか
2. 横並びBOX配置になっていないか
3. WHL系がTPU一体タイヤとして扱われているか
4. フロート部品が印刷対象に含まれているか
5. RCP-G1操作パネルがPTOと干渉しない位置にあるか
6. PTOユニット装着時でも緊急停止ボタンを押せるか
7. フロートとタイヤが干渉しないか
8. ギアボックス内部模型の向きが左右で合っているか
9. 配線穴・上部ノッチが水面に近づきすぎないか
10. 水試験では電子部品を外しているか
```

---

### 水槽・たらい浮力試験の推奨手順

最初の水試験では、電子部品を搭載しないでください。

推奨手順:

```text
1. LOWER-FRAME、タイヤ、フロート、HULL-SKIDを組む
2. BBOX/CBOXを載せる
3. 電子部品の代わりに重りを入れる
4. 15cm水深のたらい・浴槽・水槽に入れる
5. 静止時の水線を確認する
6. 前後に傾ける
7. 左右に傾ける
8. 軽く揺らす
9. 配線穴・フタ・BOX底面に水が近づくか確認する
10. 浮力不足ならフロート・発泡材・前後浮力体を追加する
```

合格目安:

```text
- BOX底面が水面に近づきすぎない
- 上部配線穴 / ノッチに水が届かない
- 前後どちらかだけ大きく沈まない
- 左右に傾けても復元する
- フロートがタイヤの回転を邪魔しない
- 回収しやすい
```

---

### 画像・説明図について

このフォルダに含まれる組み立て説明画像は、視覚的な補助資料です。

正式な部品名・寸法・印刷対象は、以下を正としてください。

```text
STL
STEP
print_manifest
plate_manifest
design_contract
CadQuery source
```

画像内の一部ラベルや形状は、模式図・簡略表記を含む場合があります。

---

### 既知の注意点

- 一部の自動生成CSVやレポートファイル名に、古い `v2_25` 表記が残っている場合があります。
- 部品番号が `PS-RV227-...` になっているものをv2.27部品として扱ってください。
- GitHub公開時は、README内でこの注意点を明記してください。
- 実機投入前には、必ず新しい設計レビューを行ってください。

---

### 推奨フォルダ構成

例:

```text
rover_v227/
  README.md
  rover_v227_out/
  rover_v227_dense_v5_7_model/
  docs/
  images/
  src/
```

可能であれば、以下も追加してください。

```text
src/
  paddy_swarm_common_rover_v2_27_cadquery.py
  paddy_swarm_a1_dense_project_tools_v5_7.py

docs/
  SAFETY.md
  PRINTING.md
  ASSEMBLY.md
  FLOAT_TEST.md
  CHANGELOG.md
```

---

### ライセンス・利用条件

現時点では試作・検証用データです。

公開ライセンスを設定する場合は、別途 `LICENSE` ファイルを追加してください。

ライセンス未設定のまま公開する場合、第三者が自由に再利用できるとは限らないため、GitHub上ではライセンス方針を明記してください。

---

### プロジェクトについて

Paddy Swarm Project は、家族経営・小規模稲作農家が高額な大型農機に依存しすぎず、壊れても直せる小型ロボット群を段階的に開発するためのプロジェクトです。

最初から万能ロボットを作るのではなく、まずは以下を目指します。

```text
田んぼで生き残る
水に沈まない
泥で詰まりにくい
人間が回収できる
壊れても修理できる
少しずつ作業を補助する
```

---

# Paddy Swarm Common Rover v2.27

## English

### Overview

This folder contains print and assembly data for **Paddy Swarm Common Rover v2.27**.

v2.27 is **not a field-ready rice paddy robot**.  
It is a **low-load 3D printed mockup / prototype test platform** for checking the following:

- Undercarriage assembly
- Gearbox internal mockup
- TPU integrated wheel/tire installation
- Front/rear BBOX and CBOX placement
- PTO and emergency-stop clearance
- Float module installation
- Buoyancy and posture in a 15 cm water-depth mockup test
- Interference, assembly order, and design issues

This data is not a finished product, not a waterproof guarantee, and not a field-deployable machine.

---

### Important safety notice

This v2.27 design is a low-load printed mockup for assembly, buoyancy, and fit-check testing.

Please follow these rules:

- Do not perform water tests with electronics installed.
- Do not deploy this model in a real rice field.
- Do not treat 3D printed waterproof boxes as field-ready waterproof enclosures.
- For water tests, remove batteries, boards, and motors. Use dummy weights instead.
- Float modules are mandatory for 15 cm water-depth tests.
- PTO, motor drive, battery, waterproofing, charging, and emergency-stop systems are not field-validated.
- The emergency-stop button must remain reachable even when a PTO unit is attached.
- Float modules are treated as standard equipment, but actual buoyancy must be verified by tank testing.

---

### Key v2.27 design rules

#### 1. BBOX and CBOX must be placed front-to-rear

BBOX-BDY and CBOX-BDY must not be placed side by side.

Correct layout:

```text
FRONT
  BBOX-BDY  power / battery system
  CBOX-BDY  control / communication system
REAR
```

Prohibited layout:

```text
BBOX-BDY + CBOX-BDY side by side
```

Side-by-side placement can exceed the 30 cm rice-row spacing width limit.

---

#### 2. The wheels are not designed for separate rubber tires

The following v2.27 parts are **TPU printed integrated wheel/tire mockups**:

```text
PS-RV227-WHL-FL
PS-RV227-WHL-FR
PS-RV227-WHL-RL
PS-RV227-WHL-RR
```

They are not designed to accept separate commercial rubber tires.

If commercial rubber tires are used in a future version, the wheel rim, tire inner diameter, tire outer diameter, bead geometry, and mounting method should be redesigned as a separate version.

---

#### 3. Float modules are standard equipment

Assuming 15 cm water depth plus mud sink-in, wheels and waterproof boxes alone may not provide enough freeboard.

In v2.27, the following float-related parts are treated as standard equipment:

```text
PS-RV227-FLT-L
PS-RV227-FLT-R
PS-RV227-HULL-SKID
PS-RV227-FLT-BRACKET-S
PS-RV227-FLT-RCV-L
PS-RV227-FLT-RCV-R
PS-RV227-FLT-RCV-FR-S
PS-RV227-FLT-STRAP-S
```

However, 3D printed floats may leak through layer gaps or pinholes.

For water testing, use additional sealing or buoyancy aids as needed:

- Closed-cell foam
- Sealed PET bottles
- EVA foam blocks
- Waterproof coating
- Epoxy sealing
- Urethane coating
- Silicone sealant

---

#### 4. PTO and emergency-stop must be separated

In v2.27, the PTO connection and emergency-stop button are separated.

Design intent:

- PTO remains on the lower front attachment face.
- The emergency-stop / control panel is mounted higher.
- `PS-RV227-RCP-BRKT` separates the control panel from the PTO area.
- The emergency-stop button must remain accessible even when a PTO-driven unit is installed.

---

### Recommended print sets

This folder may contain multiple dense print sets.

For the low-load moving mockup:

```text
dense_rigid_plus_metal
dense_tpu_only
```

If you are using real metal rods instead of printed rod surrogates:

```text
dense_rigid_only
dense_tpu_only
```

Important:

```text
Do not print both dense_rigid_plus_metal and dense_rigid_only.
They contain overlapping parts.
```

---

### Estimated print time and filament usage

Based on slicer screenshots, the approximate v2.27 print scale is:

```text
PETG/PLA:
  about 84h22m
  about 2781.91 g

TPU:
  about 21h05m
  about 302.32 g

Total:
  about 105h27m
  about 3084.23 g
```

Actual print time and filament usage depend on printer, nozzle size, layer height, infill, support settings, and filament type.

---

### Pre-assembly checklist

Before printing or assembly, check the following:

```text
1. BBOX and CBOX are placed front-to-rear.
2. The boxes are not placed side by side.
3. WHL parts are treated as TPU integrated wheel/tire parts.
4. Float parts are included in the print target.
5. The RCP-G1 control panel does not interfere with the PTO.
6. The emergency-stop button remains reachable with the PTO unit attached.
7. Float modules do not interfere with wheel rotation.
8. Left/right gearbox internal mockups are oriented correctly.
9. Upper wire-drop notches do not approach the waterline.
10. All electronics are removed before water testing.
```

---

### Recommended buoyancy test procedure

Do not install electronics for the first water test.

Recommended steps:

```text
1. Assemble LOWER-FRAME, wheels, float modules, and HULL-SKID.
2. Install BBOX and CBOX.
3. Add dummy weights instead of electronics.
4. Place the rover in a tub, bath, or tank with 15 cm water depth.
5. Check the waterline at rest.
6. Tilt it forward and backward.
7. Tilt it left and right.
8. Gently shake it.
9. Check whether water approaches the wire notches, lids, or box bottoms.
10. If buoyancy is insufficient, add float volume, foam, or front/rear buoyancy modules.
```

Pass criteria:

```text
- Box bottoms stay safely above the waterline.
- Upper wire notches do not contact water.
- Front or rear does not sink excessively.
- The rover self-recovers from small left/right tilts.
- Float modules do not block wheel rotation.
- The rover can be recovered easily.
```

---

### Assembly images and diagrams

Assembly images included in this folder are visual guides only.

The following files are the source of truth for official part names, dimensions, and print targets:

```text
STL
STEP
print_manifest
plate_manifest
design_contract
CadQuery source
```

Some labels or shapes in generated diagrams may be simplified or schematic.

---

### Known notes

- Some auto-generated CSV or report filenames may still contain an older `v2_25` suffix.
- Parts with `PS-RV227-...` part numbers should be treated as v2.27 parts.
- Please mention this clearly when publishing the folder on GitHub.
- A new design review is required before any real field deployment.

---

### Suggested folder structure

Example:

```text
rover_v227/
  README.md
  rover_v227_out/
  rover_v227_dense_v5_7_model/
  docs/
  images/
  src/
```

If possible, also include:

```text
src/
  paddy_swarm_common_rover_v2_27_cadquery.py
  paddy_swarm_a1_dense_project_tools_v5_7.py

docs/
  SAFETY.md
  PRINTING.md
  ASSEMBLY.md
  FLOAT_TEST.md
  CHANGELOG.md
```

---

### License and usage

At this stage, this is prototype and test data.

If you want to publish it under an open-source license, please add a separate `LICENSE` file.

If no license is provided, third parties may not have permission to freely reuse the data. Please state the license policy clearly on GitHub.

---

### About the project

Paddy Swarm Project aims to develop small, repairable robot swarms for small-scale and family rice farming.

The goal is not to immediately replace large agricultural machines.  
The first goal is to reduce heavy manual work step by step with low-cost, repairable, and modular robot systems.

The first milestone is not a universal rice-field robot.  
The first milestone is a rover that can:

```text
survive in a rice field
avoid sinking
avoid clogging with mud
be recovered by humans
be repaired after failure
assist work step by step
```

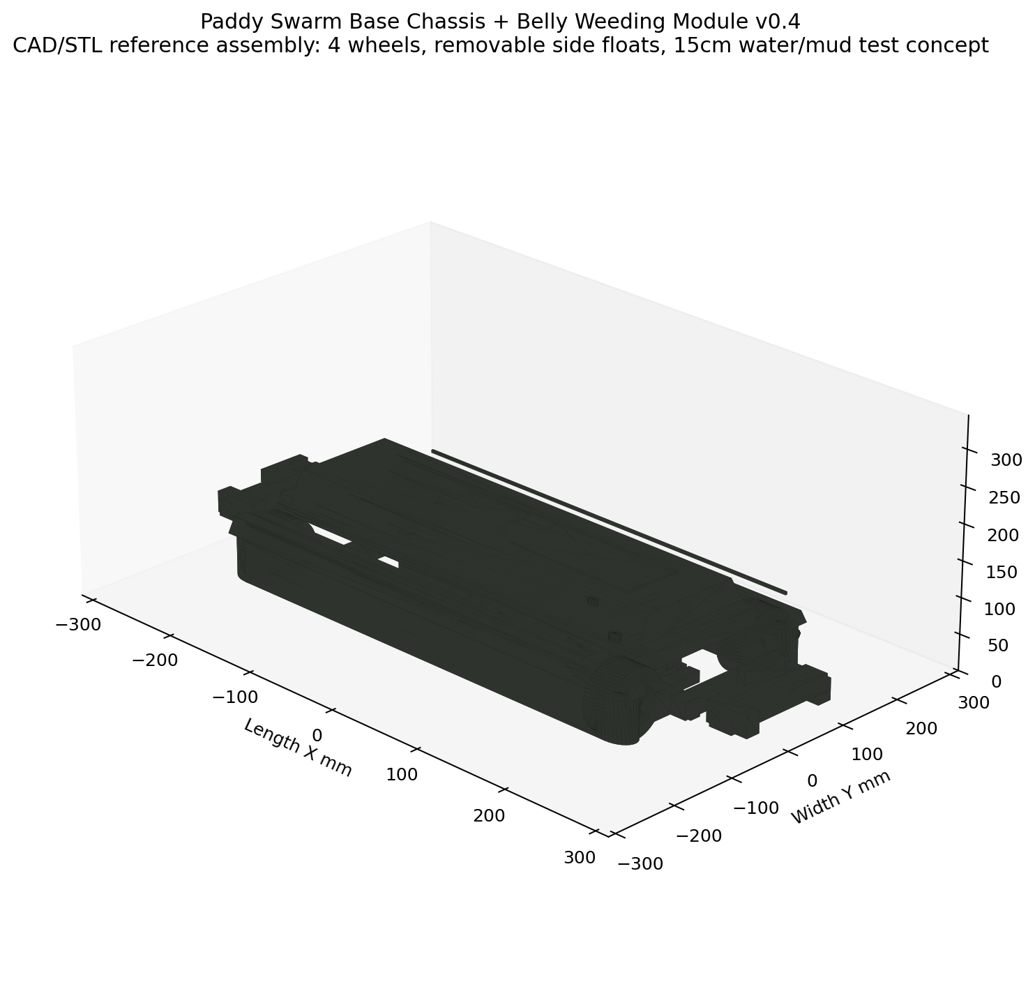
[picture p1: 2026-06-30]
paddy_swarm_weeding_platform_chassis_cad_v0_4/paddy_swarm_weeding_platform_v0_4_cad_render.png

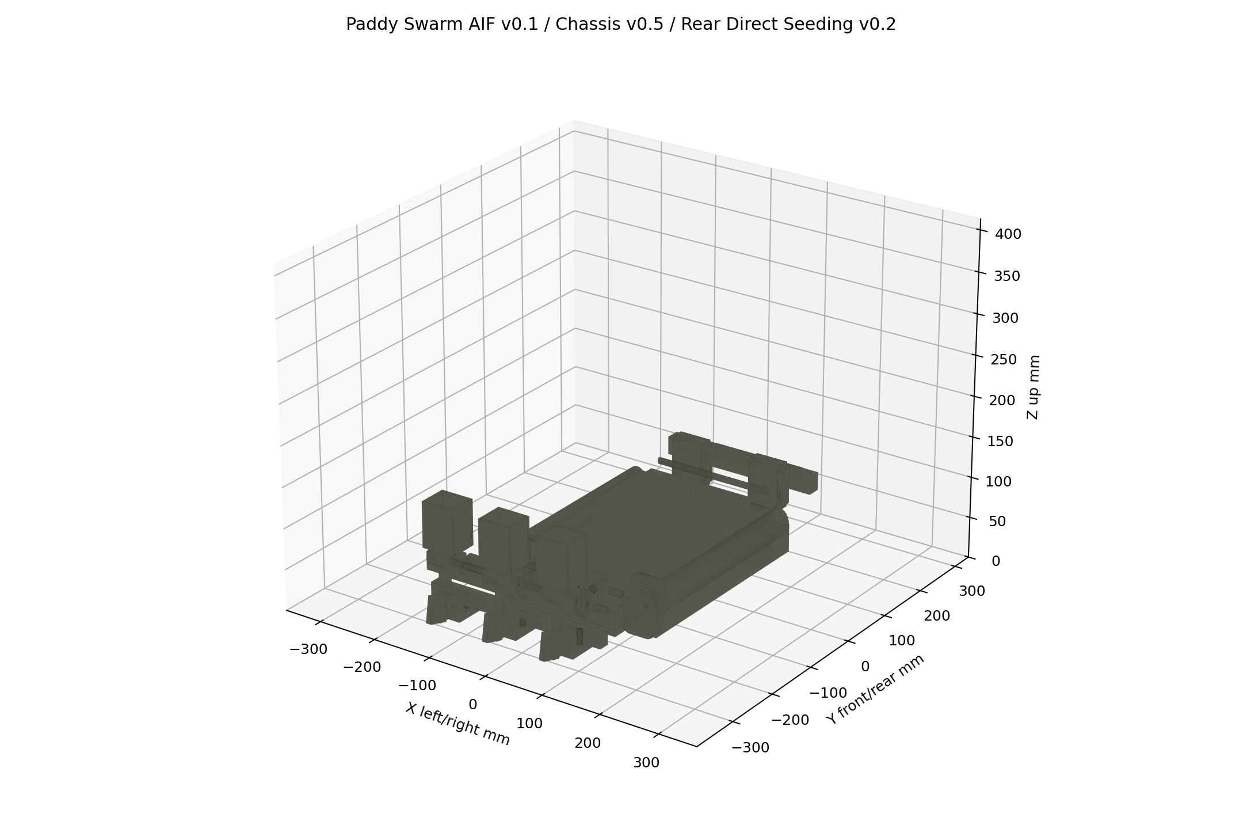
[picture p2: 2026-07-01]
paddy_swarm_attachment_interface_cad_v0_1/paddy_swarm_attachment_interface_v0_1_render.png

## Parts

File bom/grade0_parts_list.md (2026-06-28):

# Grade 0 Parts List

このファイルは今後の部品表置き場です。

## 現在の対象

- 接続テストピース
- サイドフロート断面
- ギアボックス説明模型
- 防水BOXダミー
- ローバー半身モデル

## 記入予定項目

| Part ID | Name | Material | Purpose | Status |
|---|---|---|---|---|
| TBD | TBD | PLA/PETG | TBD | draft |

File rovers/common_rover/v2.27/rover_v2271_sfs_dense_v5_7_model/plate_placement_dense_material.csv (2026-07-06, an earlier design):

plate_no | plate_name | material | part_id | filename | instance | plate_group | module | rotated_90 | x_min | y_min | x_max | y_max | bbox_x | bbox_y | bbox_z | support_orientation | support_orient_mode | printed_status | slice_status | assembly_status | notes
1 | 01_SFS-RIGID-01 | RIGID | PS-RV2271-SFS-CENTER-F | PS-RV2271-SFS-CENTER-F.stl | 1 | SFS-RIGID-01 | v2271_summer_float_shell | False | -116.0 | -116.0 | 78.0 | 116.0 | 194.0 | 232.0 | 56.675 | AXIS24_00 | auto-flat | not_printed | not_sliced | not_assembled | Do not attach to BBOX directly; use clamps/adapters. Keep clear of DRC/DRIVE.
2 | 02_SFS-RIGID-01 | RIGID | PS-RV2271-SFS-CENTER-R | PS-RV2271-SFS-CENTER-R.stl | 1 | SFS-RIGID-01 | v2271_summer_float_shell | False | -116.0 | -116.0 | 78.0 | 116.0 | 194.0 | 232.0 | 56.675 | AXIS24_00 | auto-flat | not_printed | not_sliced | not_assembled | Do not attach to CBOX directly; use clamps/adapters. Leave E-stop visible/accesssible.
3 | 03_SFS-RIGID-02 | RIGID | PS-RV2271-SFS-JOINER-S | PS-RV2271-SFS-JOINER-S.stl | 1 | SFS-RIGID-02 | v2271_summer_float_shell | False | -116.0 | -116.0 | 32.0 | -92.0 | 148.0 | 24.0 | 7.6 | AXIS24_00 | auto-flat | not_printed | not_sliced | not_assembled | Use two straps left/right or top-side depending on actual assembly clearance.
3 | 03_SFS-RIGID-02 | RIGID | PS-RV2271-SFS-JOINER-S | PS-RV2271-SFS-JOINER-S.stl | 2 | SFS-RIGID-02 | v2271_summer_float_shell | True | 40.0 | -116.0 | 64.0 | 32.0 | 24.0 | 148.0 | 7.6 | AXIS24_00 | auto-flat | not_printed | not_sliced | not_assembled | Use two straps left/right or top-side depending on actual assembly clearance.
3 | 03_SFS-RIGID-02 | RIGID | PS-RV2271-SFS-FLT-RCV-ADAPTER-S | PS-RV2271-SFS-FLT-RCV-ADAPTER-S.stl | 1 | SFS-RIGID-02 | v2271_summer_float_shell | True | 72.0 | -116.0 | 104.0 | -52.0 | 32.0 | 64.0 | 39.8 | AXIS24_00 | auto-flat | not_printed | not_sliced | not_assembled | Use only if it clears DRC/DRIVE/tire sweep. Do not make the side shell touch gearboxes.
3 | 03_SFS-RIGID-02 | RIGID | PS-RV2271-SFS-FLT-RCV-ADAPTER-S | PS-RV2271-SFS-FLT-RCV-ADAPTER-S.stl | 2 | SFS-RIGID-02 | v2271_summer_float_shell | True | 72.0 | -44.0 | 104.0 | 20.0 | 32.0 | 64.0 | 39.8 | AXIS24_00 | auto-flat | not_printed | not_sliced | not_assembled | Use only if it clears DRC/DRIVE/tire sweep. Do not make the side shell touch gearboxes.
3 | 03_SFS-RIGID-02 | RIGID | PS-RV2271-SFS-FLT-RCV-ADAPTER-S | PS-RV2271-SFS-FLT-RCV-ADAPTER-S.stl | 3 | SFS-RIGID-02 | v2271_summer_float_shell | True | 72.0 | 28.0 | 104.0 | 92.0 | 32.0 | 64.0 | 39.8 | AXIS24_00 | auto-flat | not_printed | not_sliced | not_assembled | Use only if it clears DRC/DRIVE/tire sweep. Do not make the side shell touch gearboxes.
3 | 03_SFS-RIGID-02 | RIGID | PS-RV2271-SFS-FLT-RCV-ADAPTER-S | PS-RV2271-SFS-FLT-RCV-ADAPTER-S.stl | 4 | SFS-RIGID-02 | v2271_summer_float_shell | True | -116.0 | 40.0 | -84.0 | 104.0 | 32.0 | 64.0 | 39.8 | AXIS24_00 | auto-flat | not_printed | not_sliced | not_assembled | Use only if it clears DRC/DRIVE/tire sweep. Do not make the side shell touch gearboxes.
3 | 03_SFS-RIGID-02 | RIGID | PS-RV2271-SFS-MCR-CLAMP-S | PS-RV2271-SFS-MCR-CLAMP-S.stl | 1 | SFS-RIGID-02 | v2271_summer_float_shell | False | -76.0 | 40.0 | -42.0 | 82.0 | 34.0 | 42.0 | 23.8 | AXIS24_00 | auto-flat | not_printed | not_sliced | not_assembled | Prototype U-clamp for nominal 18 mm MCR rail. Verify rail fit before tightening/locking.
3 | 03_SFS-RIGID-02 | RIGID | PS-RV2271-SFS-MCR-CLAMP-S | PS-RV2271-SFS-MCR-CLAMP-S.stl | 2 | SFS-RIGID-02 | v2271_summer_float_shell | True | -34.0 | -84.0 | 8.0 | -50.0 | 42.0 | 34.0 | 23.8 | AXIS24_00 | auto-flat | not_printed | not_sliced | not_assembled | Prototype U-clamp for nominal 18 mm MCR rail. Verify rail fit before tightening/locking.
3 | 03_SFS-RIGID-02 | RIGID | PS-RV2271-SFS-MCR-CLAMP-S | PS-RV2271-SFS-MCR-CLAMP-S.stl | 3 | SFS-RIGID-02 | v2271_summer_float_shell | True | -34.0 | -42.0 | 8.0 | -8.0 | 42.0 | 34.0 | 23.8 | AXIS24_00 | auto-flat | not_printed | not_sliced | not_assembled | Prototype U-clamp for nominal 18 mm MCR rail. Verify rail fit before tightening/locking.
3 | 03_SFS-RIGID-02 | RIGID | PS-RV2271-SFS-MCR-CLAMP-S | PS-RV2271-SFS-MCR-CLAMP-S.stl | 4 | SFS-RIGID-02 | v2271_summer_float_shell | True | -34.0 | 0.0 | 8.0 | 34.0 | 42.0 | 34.0 | 23.8 | AXIS24_00 | auto-flat | not_printed | not_sliced | not_assembled | Prototype U-clamp for nominal 18 mm MCR rail. Verify rail fit before tightening/locking.
3 | 03_SFS-RIGID-02 | RIGID | PS-RV2271-SFS-MCR-CLAMP-S | PS-RV2271-SFS-MCR-CLAMP-S.stl | 5 | SFS-RIGID-02 | v2271_summer_float_shell | True | 16.0 | 40.0 | 58.0 | 74.0 | 42.0 | 34.0 | 23.8 | AXIS24_00 | auto-flat | not_printed | not_sliced | not_assembled | Prototype U-clamp for nominal 18 mm MCR rail. Verify rail fit before tightening/locking.
3 | 03_SFS-RIGID-02 | RIGID | PS-RV2271-SFS-MCR-CLAMP-S | PS-RV2271-SFS-MCR-CLAMP-S.stl | 6 | SFS-RIGID-02 | v2271_summer_float_shell | True | -34.0 | 42.0 | 8.0 | 76.0 | 42.0 | 34.0 | 23.8 | AXIS24_00 | auto-flat | not_printed | not_sliced | not_assembled | Prototype U-clamp for nominal 18 mm MCR rail. Verify rail fit before tightening/locking.
4 | 04_SFS-RIGID-03 | RIGID | PS-RV2271-RCP-DOGHOUSE-G1 | PS-RV2271-RCP-DOGHOUSE-G1.stl | 1 | SFS-RIGID-03 | v2271_summer_float_shell | False | -116.0 | -116.0 | -10.0 | -47.892 | 106.0 | 68.108 | 77.423 | AXIS24_00 | auto-flat | not_printed | not_sliced | not_assembled | Prototype only. Use a real waterproof panel-mount E-stop; pot/protect rear terminals.
4 | 04_SFS-RIGID-03 | RIGID | PS-RV2271-SFS-SIDE-STANDOFF-S | PS-RV2271-SFS-SIDE-STANDOFF-S.stl | 1 | SFS-RIGID-03 | v2271_summer_float_shell | True | -2.0 | -116.0 | 47.8 | -88.0 | 49.8 | 28.0 | 24.0 | AXIS24_04 | auto-flat | not_printed | not_sliced | not_assembled | Use as a clearance gauge/spacer first. Target DRC/DRIVE clearance: 8-10 mm or more.
4 | 04_SFS-RIGID-03 | RIGID | PS-RV2271-SFS-SIDE-STANDOFF-S | PS-RV2271-SFS-SIDE-STANDOFF-S.stl | 2 | SFS-RIGID-03 | v2271_summer_float_shell | True | 55.8 | -116.0 | 105.6 | -88.0 | 49.8 | 28.0 | 24.0 | AXIS24_04 | auto-flat | not_printed | not_sliced | not_assembled | Use as a clearance gauge/spacer first. Target DRC/DRIVE clearance: 8-10 mm or more.
4 | 04_SFS-RIGID-03 | RIGID | PS-RV2271-SFS-SIDE-STANDOFF-S | PS-RV2271-SFS-SIDE-STANDOFF-S.stl | 3 | SFS-RIGID-03 | v2271_summer_float_shell | True | -2.0 | -80.0 | 47.8 | -52.0 | 49.8 | 28.0 | 24.0 | AXIS24_04 | auto-flat | not_printed | not_sliced | not_assembled | Use as a clearance gauge/spacer first. Target DRC/DRIVE clearance: 8-10 mm or more.
4 | 04_SFS-RIGID-03 | RIGID | PS-RV2271-SFS-SIDE-STANDOFF-S | PS-RV2271-SFS-SIDE-STANDOFF-S.stl | 4 | SFS-RIGID-03 | v2271_summer_float_shell | True | 55.8 | -80.0 | 105.6 | -52.0 | 49.8 | 28.0 | 24.0 | AXIS24_04 | auto-flat | not_printed | not_sliced | not_assembled | Use as a clearance gauge/spacer first. Target DRC/DRIVE clearance: 8-10 mm or more.

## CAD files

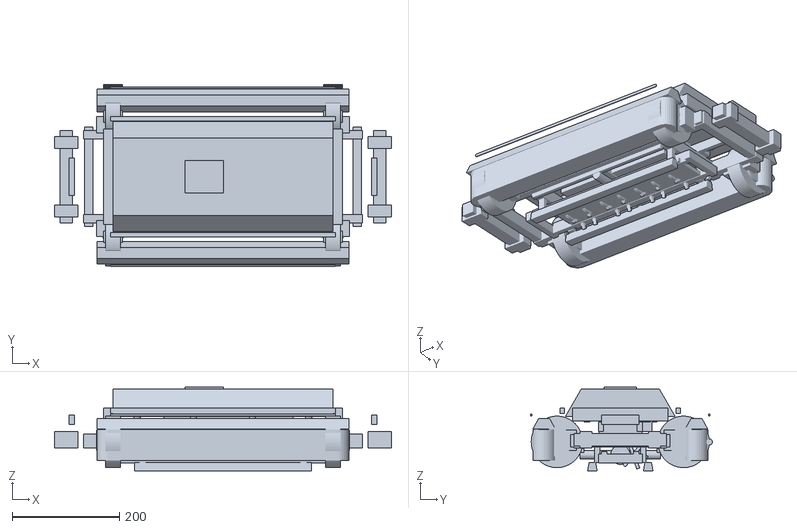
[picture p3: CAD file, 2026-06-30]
paddy_swarm_weeding_platform_chassis_cad_v0_4/stl/weeding_platform_v0_4/PSR-ASM-103-R00_base_chassis_weeding_complete_reference_assembly.stl
628.0 x 339.5 x 156.0

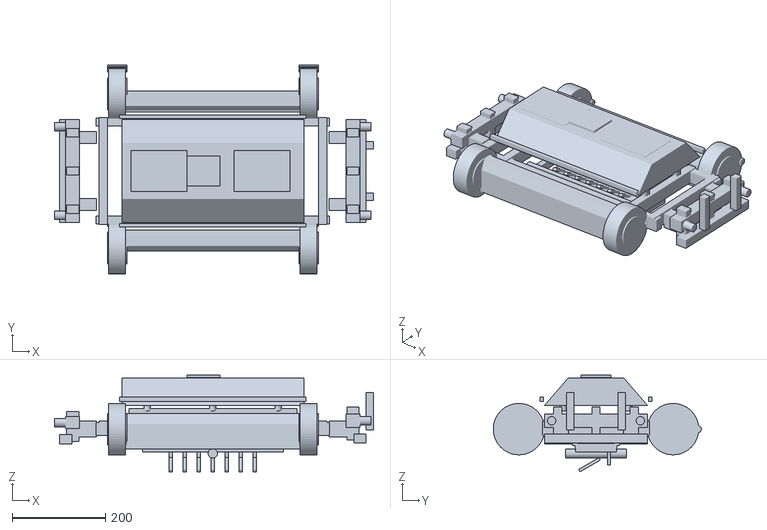
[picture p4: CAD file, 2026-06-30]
stl/work_platform_v0_3/PSR-ASM-002-R00_four_wheel_work_platform_reference_assembly.stl
683.0 x 446.4 x 206.8

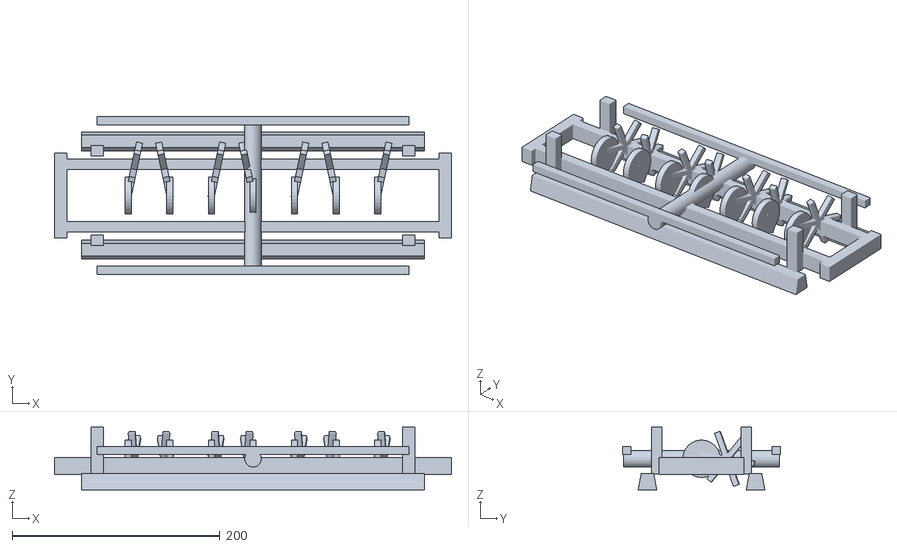
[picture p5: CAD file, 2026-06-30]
paddy_swarm_weeding_platform_chassis_cad_v0_4/stl/weeding_platform_v0_4/PSR-WD-103-R00_belly_weeding_module_complete_reference.stl
382.0 x 152.0 x 60.5

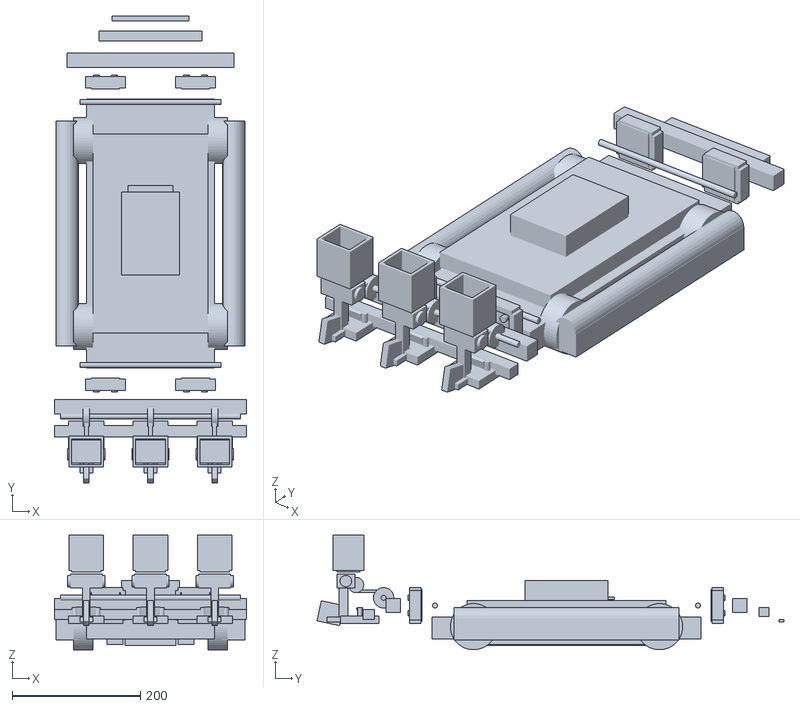
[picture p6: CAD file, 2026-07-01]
paddy_swarm_attachment_interface_cad_v0_1/stl/attachment_interface_v0_1/PSR-ASM-401-R00_chassis_v0_5_with_rear_ds_and_front_interface_reference.stl
300.0 x 727.9 x 178.5

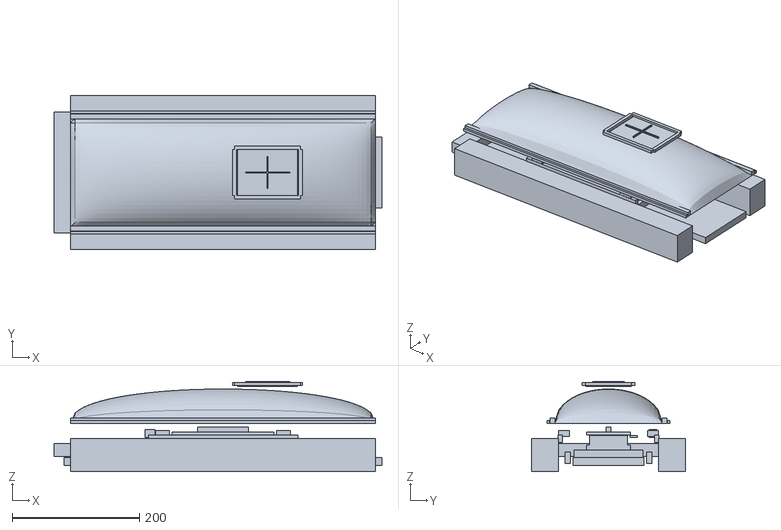
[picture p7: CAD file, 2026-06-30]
stl/hull_v0_2/PSR-ASM-001-R00_full_rover_turtle_shell_reference_assembly.stl
516.0 x 242.0 x 142.0

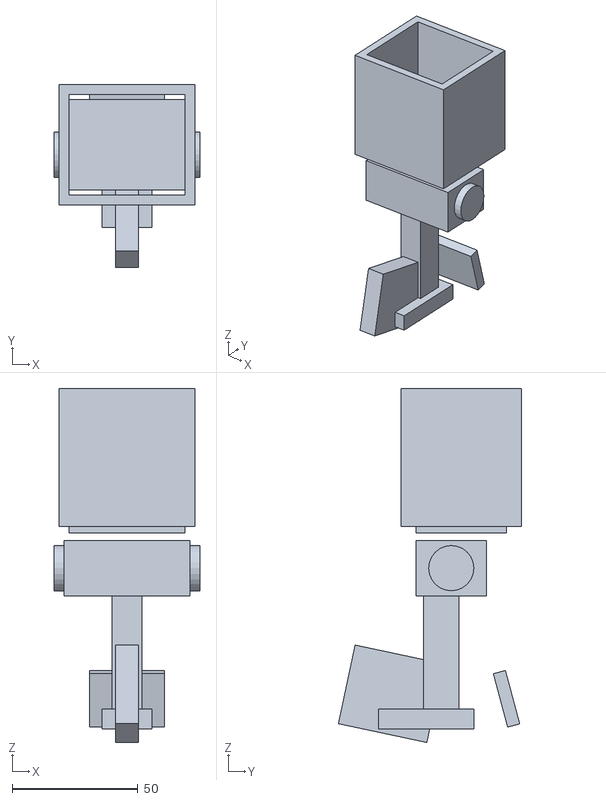
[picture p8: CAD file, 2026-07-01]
paddy_swarm_attachment_interface_cad_v0_1/stl/attachment_interface_v0_1/PSR-DS-401-R00_single_direct_seeding_unit_printable_mock.stl
58.0 x 72.9 x 140.9

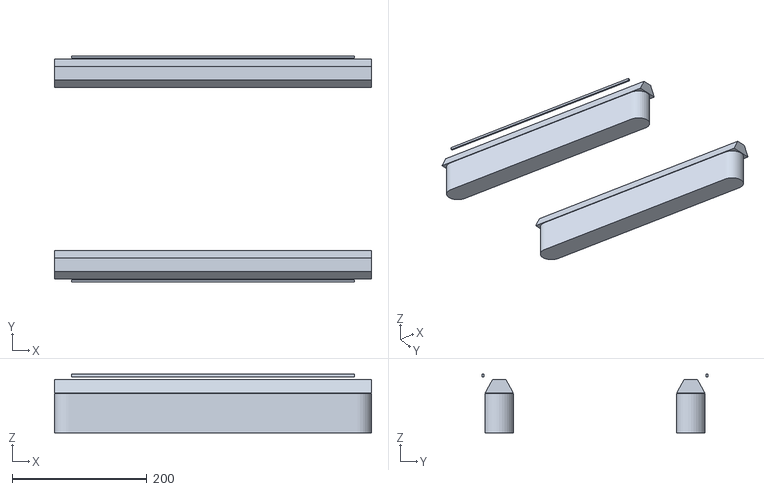
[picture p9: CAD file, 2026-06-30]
paddy_swarm_weeding_platform_chassis_cad_v0_4/stl/weeding_platform_v0_4/PSR-FLT-101-R00_removable_side_float_pair_15cm_water.stl
470.0 x 335.0 x 87.0

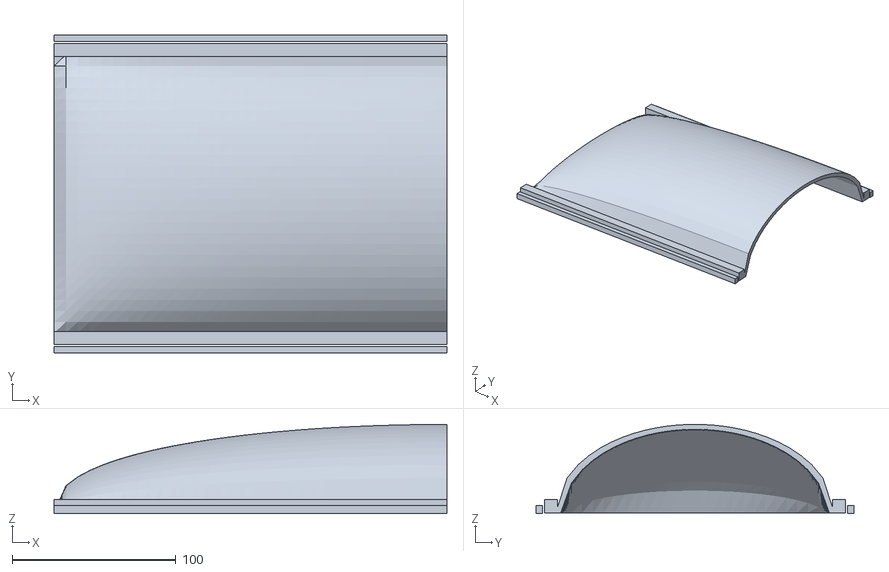
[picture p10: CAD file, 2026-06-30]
stl/hull_v0_2/PSR-SHL-001F-R00_standard_turtle_shell_front.stl
240.0 x 194.0 x 54.5

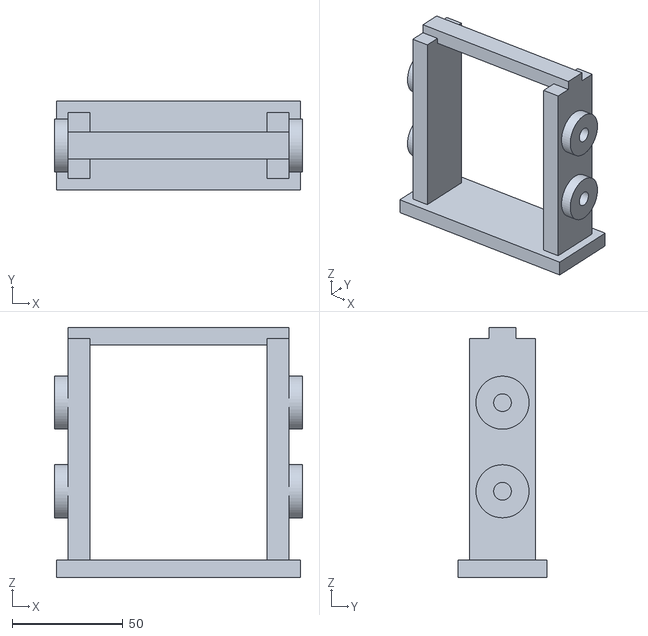
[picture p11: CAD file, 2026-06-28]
stl/PS-HU-H0-RLR-001-R00_dual_roller_side_frame.stl
112.0 x 40.0 x 113.0

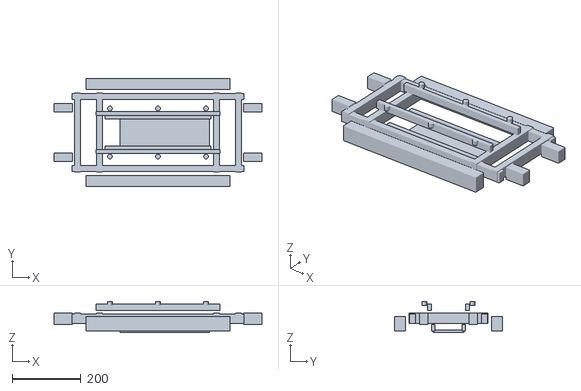
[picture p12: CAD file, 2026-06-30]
stl/work_platform_v0_3/PSR-WP-001-R00_four_wheel_work_chassis_frame.stl
606.0 x 316.0 x 91.0

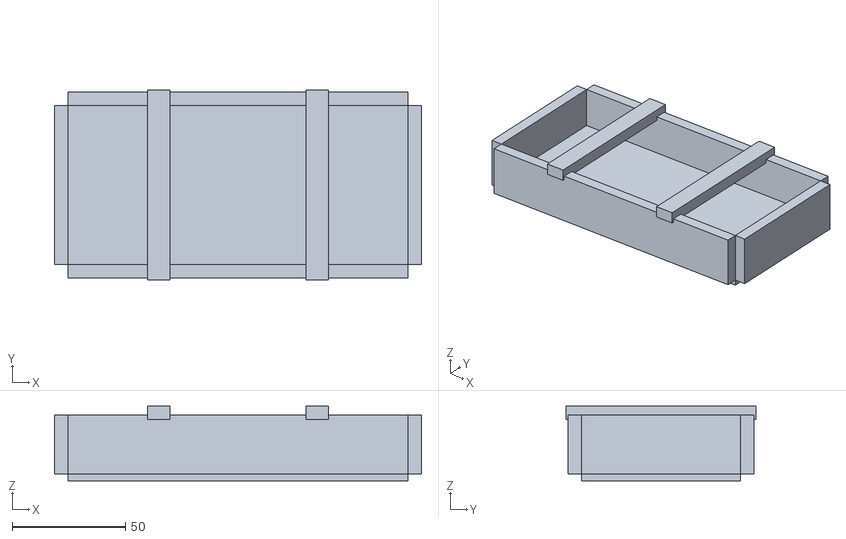
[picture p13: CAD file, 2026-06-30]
stl/hull_v0_2/PSR-PWR-011-R00_low_center_battery_tray.stl
162.0 x 84.0 x 33.0

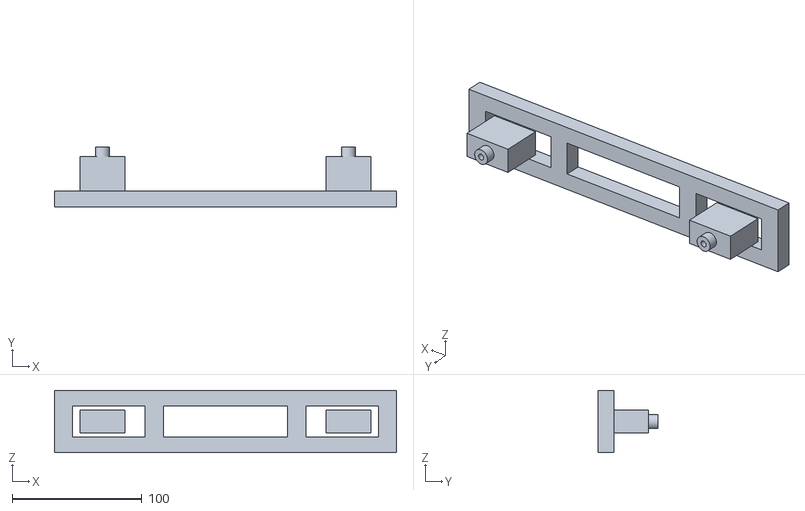
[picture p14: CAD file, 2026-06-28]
stl/PS-PR-A0-BMP-001-R00_front_bumper.stl
264.0 x 46.0 x 48.0

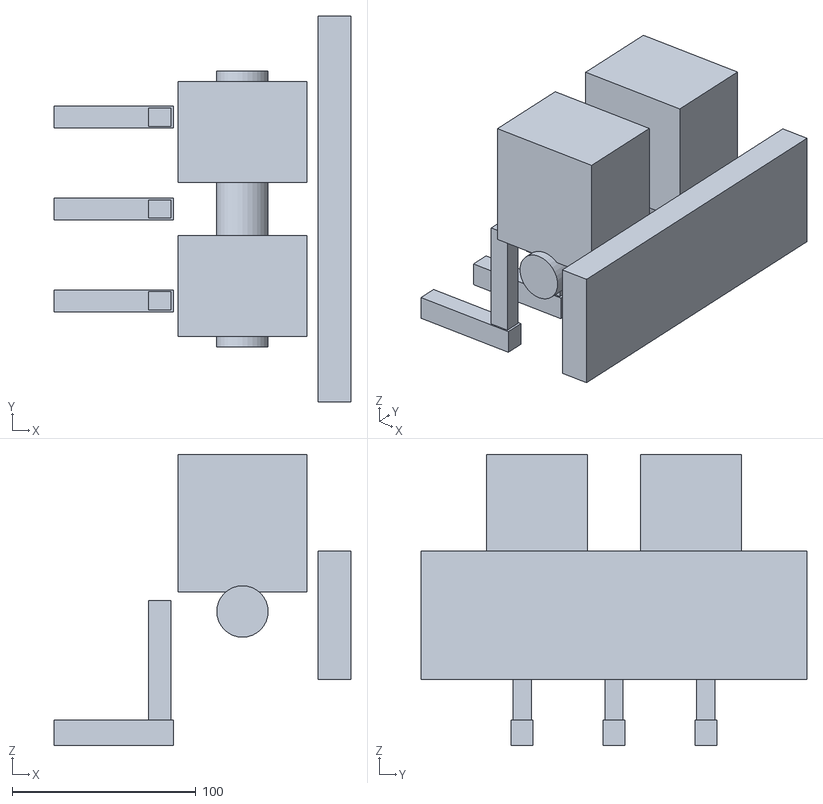
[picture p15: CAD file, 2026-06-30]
stl/work_platform_v0_3/PSR-WP-005-R00_direct_seeding_planting_module_dummy.stl
161.5 x 210.0 x 158.5

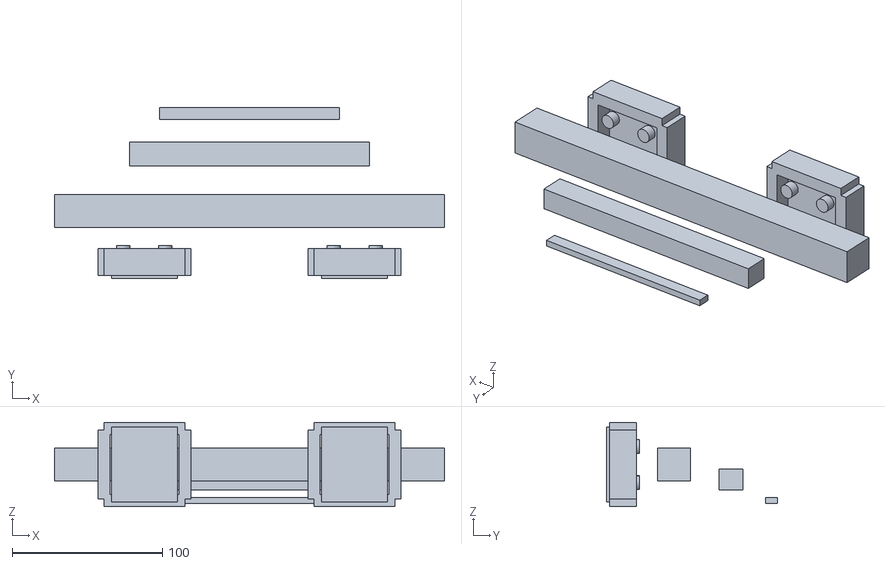
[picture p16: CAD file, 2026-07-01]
paddy_swarm_attachment_interface_cad_v0_1/stl/attachment_interface_v0_1/PSR-WP-202-R00_front_high_cut_interface_bridge_gauge.stl
260.0 x 114.0 x 56.0

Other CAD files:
paddy_swarm_weeding_platform_chassis_cad_v0_4/stl/weeding_platform_v0_4/PSR-PWR-101-R00_inner_dry_cassette_dummy.stl
stl/hull_v0_2/PSR-SHL-002-R00_solar_ready_pad_dummy.stl
stl/PS-PP-P0-TRAY-001-R00_seedling_tray_rail_section.stl
paddy_swarm_attachment_interface_cad_v0_1/stl/attachment_interface_v0_1/PSR-AIF-001-R00_attachment_interface_gauge_four_fixed_ports.stl
paddy_swarm_attachment_interface_cad_v0_1/stl/attachment_interface_v0_1/PSR-AIF-010-R00_unused_port_plug_printable_dummy.stl
paddy_swarm_attachment_interface_cad_v0_1/stl/attachment_interface_v0_1/PSR-DS-402-R00_three_unit_direct_seeding_rear_module_reference.stl
paddy_swarm_attachment_interface_cad_v0_1/stl/attachment_interface_v0_1/PSR-DS-403-R00_hopper_extension_wall_plus60_no_lid.stl
paddy_swarm_attachment_interface_cad_v0_1/stl/attachment_interface_v0_1/PSR-DS-404-R00_hopper_extension_wall_plus100_no_lid.stl
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

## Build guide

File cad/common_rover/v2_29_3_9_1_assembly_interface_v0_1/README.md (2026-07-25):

# Common Rover v2.29.3.9.1 — Assembly Interface v0.1

## 目的

Assembly Interface v0.1 は、Common Rover の部品を見ただけで、向き、接続順、固定具、荷重経路、解除方法が判断できる状態を定義する concept / fit-test lane です。製造部品の完成、購入承認、強度承認を行う lane ではありません。

旧 Grade 0 STL は、authority envelope や個別の形状確認用であり、次の要素が揃った完成組立キットではありませんでした。

- アルミ T スロットと BOX の一次固定
- フロートの slide + metal pin + R-pin 固定
- スライド後の positive stop と抜け止め
- BOX と独立した後部構造支持
- 視認可能なロック状態
- FRONT / REAR / LEFT / RIGHT を含む誤組立防止
- 一貫した組立・分解手順

そのため旧 STL を組み合わせても、完成車体としての製造、強度、耐水、現場配備は承認されません。

## Authority boundary

前方構造骨格は aluminum 20×20-class T-slot の FPB です。左右 rail と front crossmember の AI-01 は既存 authority の butt-face + metal corner bracket 接続を再確認するだけで、再設計しません。

この lane は authority と executable seed から値を読み込みます。CBOX、BBOX、battery cassette、FPB 寸法、座標軸、幅区分、slot zones を独自定数として再定義しません。

BOX は単純に FPB の上へ置くだけではありません。printed saddle で位置決めし、metal clamp と metal structural member で一次荷重を閉じる必要があります。電気コネクタは構造荷重を受けません。BBOX を CBOX だけから片持ち支持してはいけません。

## Three-layer responsibility

### A. Primary structural

- aluminum FPB / metal lower-frame concept
- metal corner brackets
- T-nuts and metal bolts
- removable metal pins
- metal R-pins or cotter-pin candidates

### B. Printed positioning and sacrificial

- CBOX / BBOX saddles
- asymmetric keys and positive-stop shoulders
- float slide guide / receiver
- drain and mud-relief paths
- replaceable wear surfaces

Printed parts may position, guide, protect, or act as a replaceable bearing interface. A printed snap or thumb latch is not the sole primary fixing for a heavy component.

### C. Secondary latch

The thumb latch is **SECONDARY ONLY**. AI-08 applies it to a lightweight service cover and coupon evaluation. It may be considered for an inspection lid, dummy, secondary anti-separation, or pin-loss cover. It may not be the primary fixing for floats, BOXes, aluminum frame, motor, PTO, or another heavy component.

## Architecture comparison

| Option | Concept | Authority / conflict result | Load path and service result |
|---|---|---|---|
| A | FPB rail-mounted CBOX saddles + independent BBOX bridge | FPB is authoritative, but CBOX rail-top attachment competes with motor/input zones; rear bridge remains HOLD | Clear front service, but rail-top competition is high |
| B | Metal front-to-rear LOWER-FRAME cradle + drop-in saddles | Best concept fit with the registered BOTTOM_SLOT lower-adapter relation; rear tie and dimensions remain HOLD | Clearest continuous metal path, open drainage, replaceable saddles |
| C | Printed undertray + metal longitudinal supports | Support attachment is unregistered and broad tray geometry is not authoritative | Higher print volume, mud retention, hidden-fastener risk |

**Recommended concept: Option B.** It is the clearest way to separate structural metal from printed positioning and preserve independent float service. This recommendation does not authorize a rear bridge or cradle manufacturing shape. The BBOX hardpoints, cradle section, attachments, stiffness, and implement clearances remain HOLD.

## Interface map

- AI-01 — FPB rails to front crossmember; existing metal corner-bracket authority only.
- AI-02 — CBOX to printed saddle and metal structural cradle.
- AI-03 — BBOX to independent rear support; manufacturing geometry HOLD.
- AI-04 — CBOX/BBOX alignment and anti-separation; not BBOX vertical support.
- AI-05 — FPB `BOTTOM_SLOT` to lower float adapter.
- AI-06 — lower adapter to keyed float slide receiver.
- AI-07 — removable metal pin plus visible metal R-pin.
- AI-08 — lightweight service-cover thumb-latch test; secondary only.
- AI-09 — battery cassette seating and latch-sequence reservation; no connector implementation.

## Human-readable markings

Every applicable concept part uses visible orientation marks:

`FRONT`, `REAR`, `LEFT`, `RIGHT`, `TOP`, `BOTTOM`

Connection marks:

`A1 / A2`, `B1 / B2`, `F1 / F2`, `L1 / L2`

Float operation:

`1 INSERT` → `2 SLIDE` → `3 LOCK` → `4 VERIFY`

LEFT and RIGHT keys are asymmetric. FRONT and REAR stops are asymmetric. Reversed insertion must not reach the final stop. Pin bores align only at the positive stop. Pin head, R-pin, clamp heads, and lock windows remain visible after assembly.

## Assembly sequence

The recommended sequence is limited to twelve steps:

1. Assemble the FPB aluminum frame.
2. Verify both metal corner brackets.
3. Install CBOX positioning saddles on the metal cradle concept.
4. Install the independent rear support concept.
5. Drop in CBOX and verify A1/A2 stops.
6. Drop in BBOX and verify B1/B2 independent seating.
7. Install the visible metal anti-separation lock.
8. Install lower float adapters on `BOTTOM_SLOT`.
9. `1 INSERT` each correctly keyed float.
10. `2 SLIDE` rearward to the positive stop.
11. `3 LOCK` with metal pin and visible R-pin.
12. `4 VERIFY` all witness marks, pin heads, R-pins, brackets, and clamps.

Disassembly is the exact reverse order. Open-ended channels, downward drains, two-sided drift access, and visible extraction faces support muddy, gloved service. Physical muddy-glove verification remains HOLD.

## Battery cassette reservation

The required order is preserved as an interface contract:

1. cassette insert
2. guide to seat
3. primary latch close
4. safety latch close
5. sensor verification
6. connector shuttle movement
7. secondary seal compression
8. low-energy signal confirmation
9. ID / voltage / polarity / temperature verification
10. pre-charge
11. voltage-difference confirmation
12. main contactor
13. drive authorization

The connector shuttle candidates are compared/reserved only. No electrical connector, seal, sensor, latch, or shuttle manufacturing geometry is created. The connector carries no structural load.

## Fit-test coupons

The generator exports exactly five small STL coupons into an external artifact directory:

1. 20×20 T-slot envelope saddle-fit coupon, 0.20/0.30/0.40/0.50 mm candidates.
2. Slide tongue/receiver coupon, 0.20/0.30/0.40/0.50 mm candidates.
3. Positive-stop pin-alignment and 6 mm-class bore coupon.
4. Secondary thumb-latch coupon with multiple thickness/gap candidates.
5. Embossed orientation, connection, and operation-marking readability coupon.

They target Bambu Lab A1 at 100% scale with support-free orientation preferred and reduced material. Every coupon is marked `FIT TEST ONLY`; COUPON-04 is also marked `SECONDARY ONLY`. They are not load-test parts and are not full rover parts. STL files must never remain in the repository.

Each coupon also carries its source-defined unique part number (`COUPON-01` through `COUPON-05`) as an engraved physical marking. Filename-only and metadata-only identification are prohibited. The engraving is placed on a non-functional +Z exterior identification band, away from fit, sliding, contact, sealing, and measurement surfaces; the XY base face is placed on the build plate so the marked face remains visible and is not consumed by support removal. No revision is appended because the source coupon-ID authority defines no coupon revision/category mapping; no repository-wide production-part category is guessed.

Generation emits `printed_part_number_audit.json`, `printed_part_number_geometry_report.txt`, and `coupon_marking_map.csv`. Validation requires five nonblank unique numbers, common-handler geometry evidence, zero floating part-number solids, matching coupon/geometry/CSV/manifest/filename records, and byte-identical coupon replay.

## Generation

Run in the `paddy-cadquery-280-py312` environment:

```text
python cad/common_rover/v2_29_3_9_1_assembly_interface_v0_1/generate_interface_package.py --output-dir <external-artifact-directory>
python cad/common_rover/v2_29_3_9_1_assembly_interface_v0_1/run_unit_tests.py --json <external-json> --text <external-text>
python cad/common_rover/v2_29_3_9_1_assembly_interface_v0_1/validate_interfaces.py --artifact-dir <external-artifact-directory> --output <external-json>
```

All SVG, JSON, CSV, Markdown reports, and STL coupons are external generated artifacts. The source lane contains Python, tests, and this README only.

## Release status

- FULL DUMMY PRINT: **HOLD**
- GITHUB EXECUTABLE CAD RELEASE: **HOLD**
- GITHUB MANUFACTURING RELEASE: **HOLD**
- MANUFACTURING: **NOT APPROVED**
- PURCHASE: **NOT APPROVED**
- WATERPROOF: **HOLD / NOT VALIDATED**
- STRUCTURAL: **HOLD / NOT VALIDATED**
- ELECTRICAL SAFETY: **HOLD / NOT VALIDATED**
- THERMAL: **HOLD / NOT VALIDATED**
- FIELD DEPLOYMENT: **HOLD / NOT APPROVED**

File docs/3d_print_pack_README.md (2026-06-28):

# Paddy Swarm 3D Print Pack v0.1 / R00 Concept Parts

This ZIP contains early **concept-level STL files** for Paddy Swarm Project prototypes.
All dimensions are in **millimeters**.

## Included prototype groups

- `Paddy Rover α-0` dry-ground basic rover parts
- `Harvest Assist H0` bench-test harvest mechanism parts
- `Paddy Planter P-0` one-row planter concept parts
- Bonus: `Station S0` dock alignment funnel concept

## Important safety status

These are **R00 concept parts**, not final load-rated engineering parts.
Do not use them directly in a real paddy field, near powered blades, or as sealed waterproof/electrical safety components without review and testing.

3D print parts are intended for:

- fit checks
- bench tests
- mockups
- low-risk dry tests
- replaceable outer parts
- guides, covers, brackets, trays, and fixtures

Use off-the-shelf or metal parts for motors, shafts, bearings, batteries, wiring, waterproof connectors, blades, and high-load structures.

## Suggested workflow

1. Print in PLA for dimension check.
2. Revise CAD dimensions after measuring real components.
3. Reprint in PETG/ASA for outdoor or repeated testing.
4. Use PA12/SLS or metal only after failure points are known.
5. Assign each printed part a visible part number before field testing.

## Part numbering rule

`PS-[MACHINE]-[STAGE]-[CATEGORY]-[NUMBER]-[REV]`

Example:

`PS-PR-A0-SBC-001-R00`

- `PS` = Paddy Swarm
- `PR` = Paddy Rover
- `A0` = Alpha-0
- `SBC` = single-board computer mount
- `001` = part number
- `R00` = revision 00

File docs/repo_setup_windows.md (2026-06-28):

# docs/repo_setup_windows.md

# WindowsでPaddy Swarm Projectのpublic repoを作る手順

この手順は、`C:\Paddy_Swarm_Project` をGitHubのpublic repositoryとして公開するためのメモです。

## 0. 前提

インストール済みであること：

- Git
- GitHub CLI `gh`

確認コマンド：

```powershell
git --version
gh --version
```

GitHub CLIにログインしていない場合：

```powershell
gh auth login
```

---

## 1. このZIPを展開する

`paddy_swarm_public_repo_files_v0_1.zip` を `C:\Paddy_Swarm_Project` に置いて、PowerShellで以下を実行します。

```powershell
cd C:\Paddy_Swarm_Project
Expand-Archive -Path .\paddy_swarm_public_repo_files_v0_1.zip -DestinationPath . -Force
```

この時点で、以下のような構成になります。

```text
C:\Paddy_Swarm_Project
├── README.md
├── CONTRIBUTING.md
├── .gitignore
├── docs/
├── stl/
├── cad/
├── bom/
├── experiments/
├── software/
├── images/
├── tools/
├── print_manifest.csv
└── kit_index.csv
```

元の `paddy_swarm_3d_print_pack_v0_1.zip` は `.gitignore` によりGit管理対象から外れます。

---

## 2. Gitリポジトリ化する

```powershell
cd C:\Paddy_Swarm_Project
git init
git branch -M main
git status
```

---

## 3. 初回コミット

```powershell
git add .
git commit -m "Initial public Grade 0 release"
```

---

## 4. GitHub CLIでpublic repoを作ってpushする

リポジトリ名を `Paddy_Swarm_Project` にする場合：

```powershell
gh repo create Paddy_Swarm_Project --public --source=. --remote=origin --push
```

これでGitHub上にpublic repoが作成され、現在のフォルダ内容がpushされます。

---

## 5. 既にGitHub側でrepoを作った場合

GitHubのWeb画面で空のrepositoryを作成済みの場合は、以下を使います。  
`YOUR_GITHUB_ID` は自分のGitHubアカウント名に置き換えてください。

```powershell
git remote add origin https://github.com/YOUR_GITHUB_ID/Paddy_Swarm_Project.git
git push -u origin main
```

---

## 6. 公開前チェック

```powershell
git status
git log --oneline -5
```

確認すること：

- 個人情報が入っていない
- 正確な田んぼ位置情報が入っていない
- 家族・近隣・ナンバープレートが写った画像がない
- 危険な試験を推奨する文章になっていない
- 元のZIPや巨大ファイルを重複コミットしていない

---

## 7. 次回以降の更新

```powershell
git status
git add .
git commit -m "Update docs and test notes"
git push
```

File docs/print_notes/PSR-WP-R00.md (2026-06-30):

# PSR-WP R00 印刷メモ

## 推奨材料

- 寸法確認：PLA
- 本体・フロート・カバー試験：PETG
- タイヤ・パッキン・ラグ：TPU

## 初回印刷順

1. `PSR-WP-001-R00_four_wheel_work_chassis_frame.stl`
2. `PSR-WP-002-R00_front_quick_attachment_mount.stl`
3. `PSR-WP-003-R00_rear_high_cut_arm_mount.stl`
4. `PSR-WP-004-R00_belly_weeding_module_carrier_dummy.stl`
5. `PSR-WP-007-R00_low_functional_protective_cover_charge_solar_ready.stl`
6. `PSR-WH-010-R00_tpu_lug_wheel_dummy.stl`

## 注意

- `PSR-ASM-002` は全体参照用。基本的に一体印刷しない。
- 腹下除草モジュールはタインが折れやすいので、最初はスケール確認用。
- 実バッテリーや実基板は載せない。
- 水槽試験は電装なしで行う。

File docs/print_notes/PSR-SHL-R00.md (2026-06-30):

# Print Notes: PSR-SHL / Turtle Shell v0.2

## Suggested print settings

For PLA fit checks:

- 0.4 mm nozzle
- 0.20 mm layer height
- 3 walls
- 15-20% infill
- supports as needed

For PETG water-adjacent shell tests:

- 0.4 or 0.6 mm nozzle
- 0.20-0.28 mm layer height
- 4 walls
- 15-25% infill
- avoid making the shell heavy

## Key principle

The turtle shell should be light. It protects by deflecting water and mud, not by becoming a heavy pressure vessel.

## Do not

- Do not install electronics under a shell-only waterproof assumption.
- Do not place lithium batteries in the shell roof.
- Do not place metal fasteners near the Charge Scute coil zone.
- Do not make flat top surfaces that hold water.

## First print order

1. Shell mount base gauge
2. Center chassis segment
3. Inner dry cassette dummy
4. Front shell half
5. Rear shell half
6. Charge Scute insert

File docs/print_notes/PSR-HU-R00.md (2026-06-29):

# docs/print_notes/PSR-HU-R00.md

# Print Notes: PSR-HU-R00 Amphibious Hull Parts

## Recommended first settings

```text
Material first test: PLA
Material water test: PETG
Nozzle: 0.4mm
Layer height: 0.20mm
Walls: 3–4
Infill: 15–25% for frame parts
Supports: none expected for most parts
Brim: recommended for tall float trays
Scale: 100%
Unit: mm
```

## Float trays

Print open side up. These are tall narrow parts, so brim is recommended.

Before water testing:

```text
1. Print one tray in PLA to check fit.
2. Print the same tray in PETG.
3. Insert foam.
4. Fit lid.
5. Use tape or silicone only for controlled tests.
6. Do not add electronics.
```

## Central hull short frame

Print flat on the bed. This is a fit/placement frame, not a final load-bearing chassis.

## Ballast test tray

Use for washers, fishing weights, bolts, or small steel plates. Secure weights with tape or zip ties during water tests.

## Waterproof box dummy

This is a dummy shape only. It is not waterproof and must not be used to hold electronics.

## Safety

If the paper towel at the waterproof-box position becomes wet during test, mark the test as failed and revise the hull.

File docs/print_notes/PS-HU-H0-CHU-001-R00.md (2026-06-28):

# PS-HU-H0-CHU-001-R00

## Name
Downward straw discharge chute

## Machine
Harvest Assist H0

## File
`stl/PS-HU-H0-CHU-001-R00_straw_discharge_chute.stl`

## Recommended material
PLA/PETG

## Suggested infill
20-35%

## Notes
For desk tests only. Smooth surfaces reduce stem snagging.

## Safety status
R00 concept part. Validate dimensions, loads, screw clearances, material durability, and failure behavior before real machine use.

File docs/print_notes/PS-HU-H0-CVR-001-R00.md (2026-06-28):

# PS-HU-H0-CVR-001-R00

## Name
Cutter safety cover frame for bench test

## Machine
Harvest Assist H0

## File
`stl/PS-HU-H0-CVR-001-R00_cutter_safety_cover_frame.stl`

## Recommended material
PETG

## Suggested infill
35-50%

## Notes
Use a clear acrylic/polycarbonate inspection plate if needed. Do not operate blades without a cover.

## Safety status
R00 concept part. Validate dimensions, loads, screw clearances, material durability, and failure behavior before real machine use.

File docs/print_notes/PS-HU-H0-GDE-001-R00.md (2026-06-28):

# PS-HU-H0-GDE-001-R00

## Name
V-shaped rice stalk guide for bench harvest test

## Machine
Harvest Assist H0

## File
`stl/PS-HU-H0-GDE-001-R00_v_rice_stalk_guide.stl`

## Recommended material
PLA for desk / PETG for repeated test

## Suggested infill
20-35%

## Notes
First geometry check. Edges should be sanded smooth to avoid snagging leaves.

## Safety status
R00 concept part. Validate dimensions, loads, screw clearances, material durability, and failure behavior before real machine use.

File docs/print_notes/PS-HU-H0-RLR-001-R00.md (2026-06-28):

# PS-HU-H0-RLR-001-R00

## Name
Dual roller side frame with bearing ring guides

## Machine
Harvest Assist H0

## File
`stl/PS-HU-H0-RLR-001-R00_dual_roller_side_frame.stl`

## Recommended material
PETG / PA12 if repeated

## Suggested infill
40-60%

## Notes
Use 8mm shafts or adapt holes by drilling. This is a bench-test holder, not a field unit.

## Safety status
R00 concept part. Validate dimensions, loads, screw clearances, material durability, and failure behavior before real machine use.

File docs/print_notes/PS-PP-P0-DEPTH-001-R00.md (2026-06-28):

# PS-PP-P0-DEPTH-001-R00

## Name
Planting depth skid gauge concept

## Machine
Paddy Planter P-0

## File
`stl/PS-PP-P0-DEPTH-001-R00_planting_depth_skid_gauge.stl`

## Recommended material
PETG / PA12

## Suggested infill
40-60%

## Notes
Concept geometry. Test in a mud box before any field use.

## Safety status
R00 concept part. Validate dimensions, loads, screw clearances, material durability, and failure behavior before real machine use.

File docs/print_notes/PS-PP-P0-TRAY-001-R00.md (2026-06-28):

# PS-PP-P0-TRAY-001-R00

## Name
Seedling tray rail section / concept holder

## Machine
Paddy Planter P-0

## File
`stl/PS-PP-P0-TRAY-001-R00_seedling_tray_rail_section.stl`

## Recommended material
PETG / ASA

## Suggested infill
30-45%

## Notes
Scale/section concept. Real seedling tray dimensions must be measured before final design.

## Safety status
R00 concept part. Validate dimensions, loads, screw clearances, material durability, and failure behavior before real machine use.

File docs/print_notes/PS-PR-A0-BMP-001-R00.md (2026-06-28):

# PS-PR-A0-BMP-001-R00

## Name
Front/rear ladder bumper, drill-to-fit mount lugs

## Machine
Paddy Rover α-0

## File
`stl/PS-PR-A0-BMP-001-R00_front_bumper.stl`

## Recommended material
PETG / ASA

## Suggested infill
35-50%

## Notes
Concept R00. Mount holes are pilot annulus guides; drill/ream for final bolts.

## Safety status
R00 concept part. Validate dimensions, loads, screw clearances, material durability, and failure behavior before real machine use.

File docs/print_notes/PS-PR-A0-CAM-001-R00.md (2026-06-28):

# PS-PR-A0-CAM-001-R00

## Name
Generic front camera cradle / protective frame

## Machine
Paddy Rover α-0

## File
`stl/PS-PR-A0-CAM-001-R00_camera_cradle.stl`

## Recommended material
PETG / ASA

## Suggested infill
30-45%

## Notes
Use foam tape or small screws. Final camera dimensions must be measured and adjusted.

## Safety status
R00 concept part. Validate dimensions, loads, screw clearances, material durability, and failure behavior before real machine use.

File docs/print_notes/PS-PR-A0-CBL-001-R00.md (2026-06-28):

# PS-PR-A0-CBL-001-R00

## Name
Cable comb guide for temporary harness routing

## Machine
Paddy Rover α-0

## File
`stl/PS-PR-A0-CBL-001-R00_cable_comb_guide.stl`

## Recommended material
PETG / TPU optional

## Suggested infill
20-35%

## Notes
Not waterproof by itself. Use inside covers or as a service loop guide.

## Safety status
R00 concept part. Validate dimensions, loads, screw clearances, material durability, and failure behavior before real machine use.

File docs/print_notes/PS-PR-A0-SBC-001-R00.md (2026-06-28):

# PS-PR-A0-SBC-001-R00

## Name
Universal Orange Pi / small SBC mount plate with standoff rings

## Machine
Paddy Rover α-0

## File
`stl/PS-PR-A0-SBC-001-R00_orange_pi_universal_mount.stl`

## Recommended material
PETG

## Suggested infill
30-45%

## Notes
Measure the exact board before use. Designed as universal drill-to-fit R00, not a certified Orange Pi One hole pattern.

## Safety status
R00 concept part. Validate dimensions, loads, screw clearances, material durability, and failure behavior before real machine use.

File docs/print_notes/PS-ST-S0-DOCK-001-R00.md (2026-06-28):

# PS-ST-S0-DOCK-001-R00

## Name
Aze dock alignment funnel concept

## Machine
Station S0

## File
`stl/PS-ST-S0-DOCK-001-R00_aze_dock_alignment_funnel.stl`

## Recommended material
PETG / ASA

## Suggested infill
35-50%

## Notes
Bonus part. For dry dock alignment tests only, not an electrical charging connector.

## Safety status
R00 concept part. Validate dimensions, loads, screw clearances, material durability, and failure behavior before real machine use.

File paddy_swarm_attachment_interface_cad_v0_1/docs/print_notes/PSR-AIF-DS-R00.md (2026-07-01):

# Print Notes: PSR-AIF / PSR-DS R00

Recommended first prints:

1. `PSR-AIF-001-R00_attachment_interface_gauge_four_fixed_ports.stl`
2. `PSR-AIF-010-R00_unused_port_plug_printable_dummy.stl`
3. `PSR-WP-203-R00_rear_direct_seeding_interface_bridge.stl`
4. `PSR-DS-401-R00_single_direct_seeding_unit_printable_mock.stl`
5. `PSR-DS-403-R00_hopper_extension_wall_plus60_no_lid.stl`
6. `PSR-DS-405-R00_printed_pto_drive_train_rear_3unit_dummy.stl`

Use PLA for fit checks. Use PETG only after fit is confirmed. TPU may be useful for later soft seed guides and mud-contact skids.

All shafts, pins, springs and fasteners in this pack are dummy printable geometry. They are for model assembly and motion layout review only.

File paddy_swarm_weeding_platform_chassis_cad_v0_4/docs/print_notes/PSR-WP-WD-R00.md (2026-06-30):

# Print notes: PSR-WP / PSR-WD v0.4

## First print material

- PLA for fit and clearance checks
- PETG for side floats, protective cover, chassis outdoor handling
- TPU for experimental wheels and flexible tines after geometry is confirmed

## Do not print first

- Do not start with the reference assembly.
- Do not mount electronics in water tests.
- Do not treat FDM parts as waterproof without leak testing.

## Weeding-module caution

The stirrer tine geometry is a fit-test dummy. Field use requires guarded drive shafts, waterproof motor protection, emergency stop, and low-speed tests in non-crop mud first.

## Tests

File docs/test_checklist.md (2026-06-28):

# Paddy Swarm Grade 0 試験チェックリスト

この文書は、Paddy Swarm Project Grade 0で公開する3Dプリント部品・模型・試験片を、安全に印刷し、確認し、結果を共有するためのチェックリストです。

Grade 0の目的は、完成ローバーをいきなり実田んぼへ投入することではありません。  
目的は、接続方式、フロート、重心、防水BOX配置、ギアボックス模型、腹下モジュール交換構造などを、小さく安全に検証することです。

---

## 0. 最重要ルール

```text
実田んぼは収入源であり、失敗してよい実験場ではありません。
```

Grade 0では、実田んぼ投入を標準試験にしません。

試験順序：

```text
机上確認
↓
乾いた地面
↓
水槽
↓
柔らかい土
↓
浅泥
↓
水あり模擬環境
↓
小区画・非本番環境
↓
実田んぼ端部
```

---

## 1. 試験レベル

| レベル | 名称 | 内容 |
|---|---|---|
| T0 | 机上確認 | 印刷・組み立て・寸法確認のみ |
| T1 | 乾地確認 | 乾いた床・机・地面での動作確認 |
| T2 | 水槽確認 | 電装なしで浮力・傾斜・浸水確認 |
| T3 | 柔土確認 | 柔らかい土で沈み込みや抵抗を見る |
| T4 | 浅泥確認 | 浅い泥で足回り・フロートの抵抗を見る |
| T5 | 水あり模擬環境 | 模擬田んぼで水・泥・傾斜を確認 |
| T6 | 小区画確認 | 非本番・小区画で人間監視下の確認 |
| T7 | 実田んぼ端部 | 収量影響が少ない端部で限定確認 |

Grade 0の標準目標は **T0〜T2** です。

---

## 2. 試験前共通チェック

```text
[ ] 試験する部品名とバージョンを確認した
[ ] 使用材料を記録した
[ ] 印刷条件を記録した
[ ] 部品に割れ・欠け・層割れがない
[ ] 接続部が極端にきつすぎない
[ ] 接続部が緩すぎない
[ ] 無理に力を入れない
[ ] 写真を撮る準備がある
[ ] 失敗した場合に記録する準備がある
[ ] 周囲に人・動物・水濡れして困る物がない
[ ] 実田んぼではなく安全な場所で試験する
```

水を使う試験：

```text
[ ] 電装部品を載せていない
[ ] バッテリーを載せていない
[ ] 防水BOX位置には紙タオルを入れた
[ ] 部品が沈んでも回収できる
[ ] 床が濡れても滑らないようにした
[ ] 試験後に乾燥できる場所がある
```

---

## 3. 印刷結果チェック

### 3.1 印刷条件

```text
部品名：
ファイル名：
バージョン：
使用プリンター：
使用材料：PLA / PETG / TPU / その他
フィラメントメーカー：
ノズル径：
レイヤー高さ：
壁の数：
インフィル：
スライサー：
印刷向き：
サポート：あり / なし
ブリム：あり / なし
印刷時間：
失敗の有無：
```

### 3.2 外観確認

```text
[ ] 大きな反りがない
[ ] 積層割れがない
[ ] 爪が欠けていない
[ ] ピン穴が潰れていない
[ ] スライド溝に糸引きが詰まっていない
[ ] 薄壁部分が割れていない
[ ] サポート除去で壊れていない
[ ] 部品番号や刻印が読める
```

---

## 4. 接続テストピース確認

対象例：

- `PSR_CONN_001_snap_fit_test_v0_1.stl`
- `PSR_CONN_002_slide_rail_test_v0_1.stl`
- `PSR_CONN_003_dovetail_test_v0_1.stl`
- `PSR_CONN_004_printed_pin_test_v0_1.stl`
- `PSR_CONN_005_wedge_lock_test_v0_1.stl`
- `PSR_CONN_ALL_TEST_PLATE_v0_1.stl`

### 4.1 スナップフィット

```text
[ ] 指で組める
[ ] 過度な力が不要
[ ] 組んだ後に簡単には外れない
[ ] 3回抜き差ししても折れない
[ ] 10回抜き差ししても白化が少ない
[ ] 爪の根元に割れがない
[ ] PETGでも組める
[ ] PLAとPETGで硬さの違いを記録した
```

評価：

```text
組みやすさ：1 / 2 / 3 / 4 / 5
外しやすさ：1 / 2 / 3 / 4 / 5
保持力：1 / 2 / 3 / 4 / 5
破損リスク：低 / 中 / 高
コメント：
```

### 4.2 スライドレール

```text
[ ] 最後まで差し込める
[ ] 途中で引っかからない
[ ] ガタが大きすぎない
[ ] 泥や砂が入った時の余裕を想像できる
[ ] 横方向に抜けにくい
[ ] 指で外せる
[ ] 水洗いしやすそう
```

---

## 5. サイドフロート断面チェック

```text
[ ] 密閉空気室の形が分かる
[ ] 発泡材挿入部がある
[ ] 区画壁がある
[ ] シャーシ接続レールがある
[ ] 充電窓逃がし形状がある
[ ] 水面ラインを書き込める面がある
[ ] 点検口または確認しやすい形状がある
```

浮力簡易確認：

```text
[ ] 水に浮く
[ ] 片側に極端に傾かない
[ ] 空気室に水が入りにくい
[ ] 水に沈めた後、内部に水が残らないか確認した
[ ] 発泡材を入れた場合の差を記録した
[ ] PETGで印刷した場合の浸水傾向を記録した
```

---

## 6. 防水BOX配置・傾斜浸水チェック

準備：

```text
[ ] 電装部品は載せていない
[ ] バッテリーは載せていない
[ ] 防水BOX位置に紙タオルを入れた
[ ] 実機想定位置に重しを載せた
[ ] 重しは外れないように固定した
[ ] 水面ラインを記録する準備がある
```

姿勢確認：

```text
[ ] 通常姿勢で紙タオルが濡れない
[ ] 前上がり10度で紙タオルが濡れない
[ ] 前下がり10度で紙タオルが濡れない
[ ] 左傾き10度で紙タオルが濡れない
[ ] 右傾き10度で紙タオルが濡れない
[ ] 前後左右15度で危険箇所を確認した
[ ] 軽く揺らしても防水BOX位置へ水が来ない
[ ] 片側荷重で危険箇所を確認した
```

判定：

```text
[ ] 合格：紙タオルが濡れず、水面ラインにも余裕がある
[ ] 要修正：紙タオルは濡れないが水面ラインが近すぎる
[ ] 不合格：紙タオルが濡れた、または防水BOX位置に水が来た
```

---

## 7. 失敗ログ記録

```text
日付：
部品名：
ファイル名：
バージョン：
材料：
印刷条件：
試験レベル：T0 / T1 / T2 / T3 / T4 / T5 / T6 / T7
失敗内容：
失敗したタイミング：
原因の予想：
写真：
次に直す案：
危険度：低 / 中 / 高
```

---

## 8. Issue投稿テンプレート

```text
## 試験タイトル

例：[print] PSR_CONN_001 スナップ爪がPETGで折れた

## 試験対象

部品名：
ファイル名：
バージョン：

## 試験レベル

T0 / T1 / T2 / T3 / T4 / T5 / T6 / T7

## 印刷条件

使用プリンター：
使用材料：
ノズル径：
レイヤー高さ：
壁の数：
インフィル：
スライサー：
印刷向き：
サポート：
ブリム：

## 試験内容

何を試したか：

## 結果

成功した点：
失敗した点：
危険だと思った点：

## 写真・動画

添付：あり / なし

## 改善案

こう直すと良さそう：

## 判定

合格 / 要修正 / 不合格
```

---

## 9. 推奨する初回試験セット

```text
1. PSR_CONN_ALL_TEST_PLATE_v0_1.stl をPLAで印刷
2. 同じものをPETGで印刷
3. スナップ・レール・蟻継ぎ・ピン・くさびを評価
4. 結果をIssueで共有
5. サイドフロート断面をPLAで印刷
6. サイドフロート断面をPETGで印刷
7. 電装なしで水槽浮力試験
8. 紙タオル浸水確認
9. 失敗ログを共有
```

---

## 10. 最後に

Grade 0で一番大事なのは、完成品を急ぐことではありません。

```text
小さく印刷する。
机の上で壊す。
水槽で沈める。
失敗を記録する。
田んぼで失敗しない。
```

安全に、小さく、現実的に試験してください。

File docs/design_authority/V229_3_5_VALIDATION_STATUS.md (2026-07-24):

# Common Rover v2.29.3.5 Validation Status

## Artifact authority

Artifact:

`20260723T171141_common_rover_v229_3_5_loop001_hole_authority_full_runner_wiring_closure`

Result bundle SHA-256:

`f95292ffd325ccf6e61382db5cef5f9920ac819fac45557c35f3dcb150460725`

Independent ZIP inspection:

- ZIP entries: 233
- SHA256SUMS targets: 232
- internal hashes matched: 232/232
- proposed source/source snapshot matched: 75/75
- path traversal: 0
- absolute paths: 0
- duplicate entries: 0

## Static verification

- project-reported unit tests: 3,702
- project-reported mutation tests: 620
- deterministic replay: pass
- clean replay: pass
- package final seal: pass

## Runner classification

`FULL_RUNNER_STATUS = STATICALLY_WIRED_NOT_CADQUERY_EXECUTED`

`EXECUTION_RUNNER = EXPERIMENTAL_PREFLIGHT_SOURCE`

The runner must not be represented as an executed or manufacturing-qualified CAD pipeline.

## Current seeds

`EXECUTABLE_UPPER_CAD_SEED = NONE_NOT_EXECUTED`

`MANUFACTURING_CAD_SEED = NONE`

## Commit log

2026-06-28 Initial public Grade 0 release
    [PS-HU-H0-CHU-001-R00_straw_discharge_chute.stl, PS-HU-H0-CVR-001-R00_cutter_safety_cover_frame.stl, PS-HU-H0-GDE-001-R00_v_rice_stalk_guide.stl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]
2026-06-29 Add amphibious hull Grade 0 CAD pack v0.1
    [PSR-HU-001-R00_central_hull_short_frame.stl, PSR-HU-002-R00_left_float_front_tray.stl, PSR-HU-003-R00_left_float_mid_tray.stl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]
2026-06-30 Add standard turtle shell chassis CAD v0.2
    [PSR-ASM-001-R00_full_rover_turtle_shell_reference_assembly.stl, PSR-CHG-003-R00_top_wireless_charge_window_dummy.stl, PSR-HU-020-R00_center_chassis_segment_v0_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]
2026-06-30 Add four-wheel work platform chassis CAD v0.3
    [PSR-ASM-002-R00_four_wheel_work_platform_reference_assembly.stl, PSR-WH-010-R00_tpu_lug_wheel_dummy.stl, PSR-WP-001-R00_four_wheel_work_chassis_frame.stl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]
2026-06-30 Add base chassis and belly weeding CAD v0.4
    [PSR-ASM-103-R00_base_chassis_weeding_complete_reference_assembly.stl, PSR-FLT-101-R00_removable_side_float_pair_15cm_water.stl, PSR-PWR-101-R00_inner_dry_casse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]
2026-07-01 Add attachment interface standard and rear direct seeding CAD v0.1
    [PSR-AIF-001-R00_attachment_interface_gauge_four_fixed_ports.stl, PSR-AIF-010-R00_unused_port_plug_printable_dummy.stl, PSR-ASM-401-R00_chassis_v0_5_with_rear_d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]
2026-07-05 Add common rover v2.27 float-test prototype
    [01_01_rigid_A1-HARD-01_rigid.3mf, 01_01_tpu_A1-TPU-01_tpu.3mf, 02_02_rigid_A1-HARD-01_rigid.3mf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]
2026-07-06 Add v2.27 summer float shell retrofit prototypes
    [01_01_SFS-G2-P01-ROOF-F_rigid.3mf, 01_01_SFS-RIGID-01_rigid.3mf, 02_02_SFS-G2-P02-ROOF-R_rigid.3mf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]
2026-07-06 Add common rover v2.28.2 dual PTO restart prerelease
    [01_01_rigid_all_dense_rigid.3mf, 01_01_tpu_all_dense_tpu.3mf, 02_02_rigid_all_dense_rigid.3mf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]
2026-07-23 docs(cad): publish common rover v2.29.3.5 design authority snapshot
    [bom_candidate.csv, loop001_fastener_requirement_authority.csv, loop001_group_authority_audit.csv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]
2026-07-24 docs(cad): freeze common rover v2.29.3.9.1 design authority
2026-07-24 feat(cad): add Common Rover v2.29.3.9.1 executable seed
2026-07-25 feat(cad): add assembly interface and progressive dry dummy
2026-07-25 feat(cad): add production-intent input audit
2026-07-25 fix(cad): canonicalize baseline inventory hash
2026-07-25 feat(cad): register MISUMI aluminum profile inputs
